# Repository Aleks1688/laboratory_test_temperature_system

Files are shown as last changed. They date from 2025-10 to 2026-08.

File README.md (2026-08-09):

# 🔬 Laboratory Test Temperature System

**Многоканальный контроллер для тестирования термопар в лабораторных условиях**




---

## 📋 Описание проекта

Устройство предназначено для **циклического измерения температуры до 10 термопар** (K-type) с передачей данных по MQTT. 

### Ключевая особенность — работа под высоким напряжением ⚡

Термопары устанавливаются **непосредственно на выводы LED и других компонентов**, которые находятся под потенциалом **400–500 В** (фаза сети 230 В AC или повышающий преобразователь LED-драйверов). Поэтому:

- **Оба провода каждой термопары (TC+ и TC-) коммутируются через DPDT реле**
- Полная **гальваноразвязка** между высоковольтной стороной термопар и низковольтной частью (ESP32)
- Питание датчика MAX31856 — от **изолированного DC-DC** (TMA-0505)
- SPI-сигнал проходит через **цифровой изолятор ISO7741**
- PCB спроектирована с учётом **creepage/clearance** для усиленной изоляции

---

## 🏗 Архитектура системы

```
┌────────────────────────── ЗОНА ВЫСОКОГО НАПРЯЖЕНИЯ ───────────────────────────┐
│                                                                                 │
│   Термопара 1 (400-500В) ──┐                                                    │
│                            ├── IM03GR (DPDT) ───┬── [100Ω] ──┬── MAX31856 T+ │
│   Термопара 1 (400-500В) ──┘                    │           │                │
│                                                 ├── IM03GR    ├── [100Ω] ──┼── MAX31856 T- │
│   Термопара 2 ...                                │           │                │
│   ...                                            GND(A)     C_filter          │
│   Термопара 10                                                       │         │
│                                                              ┌────────────┐  │
│                                                              │  MAX31856  │  │
│                                                              │ (SPI slave)│  │
│                                                              └─────┬──────┘  │
│                                                                    │ SPI      │
│                                                        ┌───────────▼────────┐ │
│                                                        │     ISO7741        │ │
│                                                        │ (4ch digital iso)  │ │
│                                                        └───────────┬────────┘ │
├────────────────────────── ЗОНА НИЗКОГО НАПРЯЖЕНИЯ ─────────────────────────────┤
│                                                                    │ SPI      │
│                                                        ┌───────────▼────────┐ │
│                                                        │     ESP32-J2       │ │
│                                                        │  WiFi + MQTT       │ │
│                                                        └────────────────────┘ │
│                                                                                 │
│  Изолированное питание: +5V ──► TMA-0505 ──► ±5V_iso ──► MAX31856 + катушки  │
│                                                                                 │
└─────────────────────────────────────────────────────────────────────────────────┘
```

---

## 🧩 Схема электрическая принципиальная

### Основные компоненты

| Компонент | Тип | Назначение | Кол-во |
|---|-----|---|---|
| **ESP32-J2** | Модуль Wi-Fi/Bluetooth SoC | Главный контроллер, WiFi, MQTT | 1 |
| **MAX31856** | АЦП термопар | Преобразование температура→цифра (SPI) | 1 |
| **ISO7741** | Цифровой изолятор | Гальваноразвязка SPI (4 канала) | 1 |
| **IM03GR** | Сигнальное реле DPDT | Коммутация TC+ и TC- каждого канала | **10** |
| **TMA-0505** | DC-DC изолированный | ±5V изолированное питание | 1 |
| **MIC5205-2.5** | LDO | 5V → 2.5V (референс MAX31856) | 1 |
| **AO3401A** | P-MOSFET | Ключ питания аналоговой части | 1 |
| **74HC595D** | Сдвиговый регистр | Управление 20 LED индикаторами | 1-2 |

### Драйвер реле (на канал)

Каждое реле IM03GR управляется через NPN-транзистор:

```
GPIO ESP32 ──[1kΩ]──┬── NPN (BC847 / MMBT3904)
                    │         │
                   GND       Collector ──[Катушка IM03GR]── +5VA_iso
                                          │
                                    [Flyback 1N4148W]
```

- Ток катушки IM03GR = **28 мА** (5V / 178Ω) → GPIO ESP32 не тянет напрямую!
- Flyback диод защищает транзистор от выброса ЭДС самоиндукции

---

## 💡 Индикация

У каждого разъёма термопары — **2 светодиода**:

| Цвет | Значение | Условие |
|---|---|---|
| 🟢 **Зелёный** | Канал активен, идёт замер | `currentRelay == thisChannel` |
| 🔴 **Красный** | Ошибка термопары | Fault бит от MAX31856 (обрыв, короткое замыкание) |
| ⚫ **Погашены** | Канал ждёт очереди | Default state |

LED управляются через **74HC595 сдвиговый регистр** (3 GPIO → 20 LED).

---

## 📦 BOM (Bill of Materials)

### Цифровая часть (низковольтная зона)

| Qty | Компонент | Параметры | Корпус | Примечание |
|-----|---|---|---|---|
| 1 | ESP32-J2 | Wi-Fi/BLE модуль | Модуль | Основной МК |
| 1 | MAX31856 | ADC термопар, SPI | SSOP-20 | K-type, J-type... |
| 1 | ISO7741 | 4-канальный цифровой изолятор | SOIC-16 | 5kVrms, SPI развязка |
| 1 | MIC5205-2.5YM5 | LDO 2.5V, 500mA | SOT-23-5 | Референс MAX31856 |
| 1 | AO3401A | P-MOSFET, 30V, 4A | SOT-23 | Ключ питания |
| 1 | TMA-0505S | DC-DC ±5V изолированный | SIP-4/DIP | ±5V_iso для analog part |
| 2 | 74HC595D | 8-bit shift register | SOIC-16 | Управление LED (20 шт) |

### Высоковольтная часть (зона термопар)

| Qty | Компонент | Параметры | Корпус | Примечание |
|-----|---|---|---|---|
| **10** | **IM03GR** | Реле сигнальное DPDT, 5V, 178Ω | **SMT gull-wing** | TE 1-1462037-4, 1800V изол. |
| 10 | MMBT3904 / BC847S | NPN транзистор | SOT-23 / SOT-23-6 | Драйвер катушки (28мА) |
| 10 | 1N4148W / LL4148 | Flyback диод | SOD-123 / SOT-23 | Защита от ЭДС |
| 10 | 1kΩ | Резистор базы | 0805 | |
| 10 | 100Ω | Последовательный вход TC | 0805 | Защита MAX31856 |
| 20 | LED 0603 | Зелёный + красный | 0603 | Индикация каналов |
| 20 | 470Ω – 1kΩ | Резисторы LED | 0805 | I_LED ≈ 2-3мА |

### Пассивные компоненты

| Qty | Компонент | Значение | Примечание |
|-----|---|---|---|
| 4 | 0.1µF керамический | Декаплинг по питанию | 0603/0805 |
| 4 | 0.01µF – 0.1µФ | Фильтр входов TC | 0603 |
| 2 | 100кΩ | Pull-up/pull-down | 0603 |

### Разъёмы и механика

| Qty | Компонент | Примечание |
|-----|---|---|
| 10 | Разъём термопары 2-pin | Штырьковой или клеммник |
| 1 | Разъём ESP32-J2 | Для программирования |
| 1 | DIN-рейка корпус | Компактный, ширина ~4-6 TE |

> **Полный BOM с артикулами поставщиков** будет добавлен после финализации схемы.

---

## ⚙️ Программная архитектура

### FreeRTOS задачи

```
┌─────────────┐    семафор     ┌──────────────────┐    семафор     ┌──────────┐
│  relayTask  │ ──────────────► │  tempSensorTask  │ ──────────────► │ mqttTask │
│  (приоритет 1)│               │  (приоритет 2)   │               │ (пrio 1) │
└─────────────┘                 └──────────────────┘                └──────────┘
      │                                 │                               │
      ▼                                 ▼                               ▼
 Циклическое                     Чтение MAX31856                  WiFi+MQTT
 переключение 10                 TC, CJ Temp, Fault               JSON publish
 реле с паузой                   Стабилизация 100ms               в топики:
 на разрядку 200ms                                                /temp/data
                                                                  /temp/status
```

### Логика работы цикла

1. **relayTask**: Все реле OFF → пауза 200мс (разрядка!) → включить следующее → семафор → ждать 5 сек
2. **tempSensorTask**: Ждёт семафор → пауза 100мс (стабилизация сигнала) → читать TC/CJ/fault → обновить LED → семафор MQTT
3. **mqttTask**: Держит соединение → получает данные → формирует JSON → публикует

### MQTT топики

| Топик | Формат | Периодичность |
|---|---|---|
| `temperature_system/data` | JSON: `{ch, temp_cj, fault, ts}` | Каждые ~5 сек (на канал) |
| `temperature_system/status` | `"online"` / `"offline"` (LWT) | При изменении |

### JSON формат данных

```json
{
  "channel": 3,
  "tc_temp": 245.67,
  "cj_temp": 32.15,
  "fault": 0,
  "timestamp": "2026-08-09T14:30:00"
}
```

Коды fault: `0`=OK, `1`=open circuit, `2`=short to GND, `3`=short to VCC.

---

## 🔌 Распиновка GPIO (новая версия, 10 каналов)

### ESP32-J2 назначение пинов

| GPIO | Функция | Зона |
|---|---|---|
| 5 | CS (MAX31856, через ISO7741) | Digital |
| 18 | MOSI (через ISO7741) | Digital |
| 19 | MISO (через ISO7741) | Digital |
| 23 | SCK (через ISO7741) | Digital |
| 32 | Relay CH1 driver | Digital out |
| 33 | Relay CH2 driver | Digital out |
| 25 | Relay CH3 driver | Digital out |
| 26 | Relay CH4 driver | Digital out |
| 27 | Relay CH5 driver | Digital out |
| 14 | Relay CH6 driver | Digital out |
| 22 | Relay CH7 driver | Digital out |
| 21 | Relay CH8 driver | Digital out |
| 17 | Relay CH9 driver | Digital out |
| 16 | Relay CH10 driver | Digital out |
| 13 | 74HC595 DATA | Digital out |
| 12 | 74HC595 CLK | Digital out |
| 15 | 74HC595 LATCH | Digital out |
| 4 | DRDY (MAX31856) | Digital in |
| 2 | FAULT (MAX31856) | Digital in |

> **Примечание:** Final pinout будет определён после трассировки PCB. Некоторые пины могут измениться.

---

## 🛠️ Сборка и прошивка

### Требования

- [PlatformIO Core](https://platformio.org/) (CLI или VS Code extension)
- [KiCad](https://www.kicad.org/) 8.x+ (для редактирования схемы/PCB)
- USB-UART адаптер для прошивки ESP32

### Прошивка

```bash
# Клонирование
git clone https://github.com/Aleks1688/laboratory_test_temperature_system.git
cd laboratory_test_temperature_system

# Создать secrets.h (см. ниже)
cp include/secrets.h.example include/secrets.h
# Отредактировать: WIFI_SSID, WIFI_PASSWORD, MQTT_SERVER_IP, etc.

# Сборка и прошивка
pio run -t upload --environment esp32dev

# Монитор последовательного порта
pio device monitor -b 115200
```

### Конфигурация WiFi/MQTT (`include/secrets.h`)

```cpp
#ifndef SECRETS_H
#define SECRETS_H

// WiFi
#define WIFI_SSID "YourNetworkName"
#define WIFI_PASSWORD "YourPassword"

// MQTT Broker
#define MQTT_SERVER_IP "192.168.x.x"
#define MQTT_SERVER_PORT 1883

#endif // SECRETS_H
```

> ⚠️ **`secrets.h` в `.gitignore`!** Не загружайте пароли в GitHub!

---

## 📐 Требования безопасности к PCB

Для рабочего напряжения **500В AC/DC** (Pollution Degree 2, лаборатория):

| Параметр | Минимум (IEC 60664-1) | Реализовано |
|---|---|---|
| Clearance (воздух между проводниками) | 2.5 мм | 3.0+ мм |
| Creepage (по поверхности PCB) | 2.5 мм | 4.0 мм + slotting |
| Между каналами термопар | 2.5 мм | **5.0 мм** (разные потенциалы!) |
| Изолированная ↔ Неизолированная зона | 4.0 мм | **6.0 мм + слот** |
| Конформное покрытие | Recommended | **Обязательно** |

### Slotting (увеличение creepage)

Между дорожками разных каналов и между зонами напряжения — **фрезерованные вырезы** в PCB:

```
  Канал 1 (TC)        ╔═══════╗        Канал 2 (TC)        ╔═══════╗
  [+] [-]             ║ ВЫРЕЗ ║        [+] [-]             ║ ВЫРЕЗ ║
    │                 ║ 2мм   ║          │                 ║ 2мм   ║
    └─────────────────╨───────╨──────────┴─────────────────╨───────╨───
                        ↑ creepage теперь через воздух (больше!)
```

---

## 📂 Структура репозитория

```
laboratory_test_temperature_system/
├── README.md                  ← Этот файл
├── platformio.ini             # Конфигурация PlatformIO (ESP32, Arduino framework)
├── .gitignore
│
├── src/                      # Исходный код прошивки
│   ├── main.cpp              # Точка входа, создание задач FreeRTOS
│   ├── relay_control.cpp     # Управление реле (цикл 10 каналов)
│   ├── temp_sensor.cpp       # Чтение MAX31856
│   └── mqtt_client.cpp       # WiFi + MQTT публикация
│
├── include/                  # Заголовочные файлы
│   ├── config.h              # Пины, тайминги, константы
│   ├── secrets.h.example     # Шаблон для WiFi/MQTT (см. secrets.h)
│   ├── relay_control.h
│   ├── temp_sensor.h
│   └── mqtt_client.h
│
├── lib/                      # Локальные библиотеки (пока пусто)
│
├── test/                     # Unit-тесты PlatformIO
│
├── hardware/                 # KiCad проект (СКОРО)
│   ├── temperature_controller.kicad_pro
│   ├── temperature_controller.kicad_sch
│   ├── temperature_controller.kicad_pcb
│   └── libs/                 # KiCad символы/footprints
│       ├── IM03GR.kicad_sym
│       ├── IM03GR.kicad_footprint
│       └── ...
│
├── docs/                     # Документация и даташиты
│   ├── IM03GR_datasheet.pdf      # AXICOM/TE реле (НОВОЕ)
│   ├── CPC2014N_datasheet.pdf    # Старое SSR реле (для истории)
│   ├── ISO7741_datasheet.pdf     # Цифровой изолятор
│   ├── TMA-0505_datasheet.pdf    # DC-DC изолированный
│   ├── MAX31856_datasheet.pdf    # АЦП термопар
│   └── images/
│       ├── schematic.png          # Принципиальная схема
│       ├── pcb_top.png            # PCB top layer
│       └── pcb_bottom.png         # PCB bottom layer
│
└── images/                   # Для README (скриншоты)
```

---

## 🔄 История изменений (Changelog)

### v2.0 — Переделка на механические реле (в процессе)
- ❌ CPC2014N SSR ×12 → ✅ **IM03GR DPDT ×10** (1800V изоляция контакт-катушка)
- ❌ 12 каналов → ✅ **10 каналов**
- ➕ **DPDT коммутация обоих проводов TC+ и TC-** (безопасность при 500В!)
- ➕ **LED индикация** на каждый канал (активный / fault)
- ➕ **Драйверы реле** (NPN + flyback диод)
- ➕ **74HC595** для управления 20 LED
- ➕ **README + документация + даташиты**

### v1.0 — Исходная версия (октябрь 2025)
- 12× CPC2014N SSR реле
- ESP32 + MAX31856 + ISO7741 + TMA-0505
- FreeRTOS задачи: relay / tempSensor / mqtt
- MQTT публикация JSON
- KiCad схема и PCB (CPC2014N_PCB.kicad_sch)

---

## ⚠️ Предупреждения

### Электробезопасность ⚡⚡⚡
Это устройство работает с **опасным напряжением 400–500 В**. При неправильной сборке или использовании существует риск:
- **Поражения электрическим током**
- **Возгорания** при пробое изоляции
- **Повреждения измерительного оборудования**

**Всегда:**
- Соблюдайте creepage/clearance расстояния на PCB
- Используйте конформное покрытие высоковольтной зоны
- Проверяйте изоляцию мегомметром перед первым включением
- Работайте под присмотром квалифицированного персонала

### Лицензия

MIT License — см. файл [LICENSE](LICENSE).

---

## 👤 Автор

**Aleks1688 (Razin)**  
Лаборатория тестирования LED-компонентов  
*Проект создан для внутренних нужд лаборатории*

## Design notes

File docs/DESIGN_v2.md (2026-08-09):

# 📐 Design Document v2.0 — Thermocouple Test Controller

## Обновлено: 2026-08-09

---

## 1. Выбор компонентов — Финализация

### 1.1 Реле: AXICOM IM03GR (TE 1-1462037-4)
| Параметр | Значение |
|---|---|
| Тип | Signal Relay, **DPDT (2 Form C / 2CO)**
| Катушка | 5V DC, **178Ω**, **28mA**, 140mW
| Контакты | PdRu+Au (золото), бифуркационные
| Номинал | **220VDC / 250VAC**, 2A max
| Изоляция контакт-катушка | **1800 Vrms** ✅
| Изоляция смежные контакты | 1000 Vrms
| Корпус | **SMT gull-wing**, 10×6×5.65mm
| Монтаж | Reflow до 260°C

**Использование DPDT:** POLE1 = TC+, POLE2 = TC- (оба провода коммутируются!)

### 1.2 Светодиоды индикации: Аксиальный Pilot LED 2×3×4.7mm
| Параметр | Значение |
|---|---|
| Тип | Axial "pilot light" LED, диффузный квадратный корпус |
| Размер | **2×3×4.7mm** (или 2×5×7mm вариант) |
| Монтаж | **Through-hole**, выводы через PCB, припаян снизу |
| Расположение | На верхней панели: отверстие Ø2-2.3mm, LED снизу, светит вверх |
| Цвета | 🟢 Зелёный (активный канал), 🔴 Красный (fault) |
| Ток | ~2-5мА (резистор 680Ω-1.5kΩ от 3.3V или 5V) |

**Всего:** 10 каналов × 2 цвета = **20 LED**

### 1.3 Драйвер реле: NPN транзистор
| Параметр | Значение |
|---|---|
| Тип | **BC847S** (dual NPN в SOT-23-6) или **MMBT3904** (SOT-23) |
| Ic max | 500mA (достаточно для 28мА катушки) |
| hFE | >100 (при Ic=10мА) → Ib < 0.3мА от GPIO |
| Резистор базы | **1kΩ** (Ib ≈ 2.6мА при 3.3V GPIO) |
| Flyback диод | **1N4148W** (SOD-123) или **LL4148** (MELF) |

**BC847S = 2 NPN в одном корпусе** → 5 штук на 10 реле вместо 10 отдельных!

### 1.4 Драйвер LED: 74HC595 сдвиговый регистр
| Параметр | Значение |
|---|---|
| Тип | **74HC595D** (SOIC-16) или **74HC595PW** (TSSOP-16) |
| Количество | **3 штуки** (3×8bit = 24 бита, используем 20) |
| Подключение | Каскадом: QH'→DS следующего |
| Управление | **3 GPIO**: DATA (SER), CLK (SRCLK), LATCH (RCLK) |
| Напряжение | 3.3V логика от ESP32 (HC-серия tolerant) |
| Ток вывода | ±6mA (хватит для LED через резистор) |

**Распределение бит 74HC595:**
```
Chip 1 (Q0-Q7):   CH1_ACTIVE, CH2_ACTIVE, CH3_ACTIVE, CH4_ACTIVE, CH5_ACTIVE, CH6_ACTIVE, CH7_ACTIVE, CH8_ACTIVE
Chip 2 (Q0-Q7):   CH9_ACTIVE, CH10_ACTIVE, CH1_FAULT, CH2_FAULT, CH3_FAULT, CH4_FAULT, CH5_FAULT, CH6_FAULT
Chip 3 (Q0-Q1):   CH7_FAULT, CH8_FAULT, CH9_FAULT, CH10_FAULT, [свободно x4]
```

---

## 2. GPIO Map — Финальное распределение

### ESP32-J2 доступные GPIO (исключая strapping/flash):
Используем только "безопасные" GPIO без странных побочек при старте:

| GPIO | Функция | Зона | Примечание |
|---|---|---|---|
| **SPI (через ISO7741):** ||||
| 5 | CS_MAX | Digital out | MAX31856 Chip Select |
| 18 | SPI_MOSI | Digital out | → ISO7741 INA → MAX31856 SDI |
| 19 | SPI_MISO | Digital in | MAX31856 SDO → ISO7741 OUTA → GPIO19 |
| 23 | SPI_SCK | Digital out | → ISO7741 INB → MAX31856 SCK |
| **Реле (драйверы NPN):** ||||
| 32 | RELAY_CH1 | Out | → R_base Q1 → IM03GR #1 катушка |
| 33 | RELAY_CH2 | Out | → IM03GR #2 |
| 25 | RELAY_CH3 | Out | → IM03GR #3 |
| 26 | RELAY_CH4 | Out | → IM03GR #4 |
| 27 | RELAY_CH5 | Out | → IM03GR #5 |
| 14 | RELAY_CH6 | Out | → IM03GR #6 |
| 22 | RELAY_CH7 | Out | → IM03GR #7 |
| 21 | RELAY_CH8 | Out | → IM03GR #8 |
| 17 | RELAY_CH9 | Out | → IM03GR #9 |
| 16 | RELAY_CH10 | Out | → IM03GR #10 |
| **LED драйвер (74HC595 ×3):** ||||
| 13 | LED_DATA (SER) | Out | 74HC595 serial data in |
| 12 | LED_CLK (SRCLK) | Out | Shift register clock |
| 15 | LED_LATCH (RCLK) | Out | Output latch strobe |
| **MAX31856 статус:** ||||
| 4 | DRDY | Digital in | Data Ready (опционально) |
| 2 | FAULT | Digital in | Fault output от MAX31856 |
| **Питание/управление:** ||||
| 13 | PWR_KEY | Out | AO3401A gate (включить изолированную часть) |

**Итого: 10 + 3 + 4 + 2 + 2 = 21 GPIO** ← ESP32-J2 потянет легко ✅

> ⚠️ GPIO 12 (HS2_DATA2) — избегаем! Влияет на flash voltage при старте.
> GPIO 0, 2, 5, 12 — strapping pins, используем осторожно (2 и 5 OK как обычные GPIO после boot).

---

## 3. Принципиальная схема — Описание по секциям

### Секция A: Питание (верх слева на схеме)
```
+5V ──┬── C1 0.1µF ── GND
      │
      ├── U15 MIC5205-2.5YM5 (IN=5V, OUT=2.5V)
      │    IN EN OUT BP GND
      │    │   │   │   │   │
      │    +5V HI 2.5VA C8 0.1µF GND
      │              │
      │              C6 0.1µF ── GND
      │
      └── U16 TMA-0505S (изолированный DC-DC)
           Vin+ Vin- Vout+ Vout-
           │     │     │      │
          +5V   GND  +5VA   -5VA (GND_A)
                    │       │
                   C7,C8  0.1µF each to GND_A
```
- **2.5VA** → референс MAX31856 (pin BIAS)
- **±5VA (GND_A)** → питание MAX31856 + катушки реле + ISO7741 сторона B

### Секция B: ESP32-J2 модуль (центр верх)
```
J4: ESP32-J2 разъём (все GPIO выведены)
├── 3V3 (от внутреннего LDO ESP32)
├── GND
├── EN, BOOT, RXD, TXD (для прошивки)
└── GPIO 2,4,5,12-33 (как в таблице выше)
```

### Секция C: Цифровой изолятор ISO7741 (справа верх)
```
U13: ISO7741DW (SOIC-16)
 Side A (LV):            Side B (HV_iso):
 INA  ← GPIO18 (MOSI)   OUTA → MAX SDI (pin 3)
 INB  ← GPIO23 (SCK)    OUTB → MAX SCK (pin 5)
 INC  ← MAX SDO (OUTC)  → GPIO19 (MISO)
 IND  ← (GND)           OUTD → (GND_A)
 VCC1 = 3V3             VCC2 = +5VA
 GND1 = GND             GND2 = GND_A
```

### Секция D: MAX31856 + защита входов (справа низ)
```
U14: MAX31856SS (TSSOP-20)
 Питание: AVDD=+5VA, DVDD=+5VA, GND=GND_A, BIAS=2.5VA
 SPI: SDI(3), SCK(5), SDO(6), CS(4)
 Аналоговые входы:
   T+ (pin 17) ── R27 100Ω ──┬── от реле (COM→NO полюс 1)
                              ├── C3 0.01µF ── GND_A
   T- (pin 18) ── R28 100Ω ──┬── от реле (COM→NO полюс 2)
                              ├── C4 0.01µF ── GND_A
 Защита:
   D1,D2: 1N4148 (T+ → AVDD, T+ → GND_A)
   D3,D4: 1N4148 (T- → AVDD, T- → GND_A)
 Статус:
   DRDY (pin 15) → GPIO4 (ESP32)
   FAULT (pin 14) → GPIO2 (ESP32)
```

### Секция E: 10× Реле IM03GR + драйверы (левая половина схемы)
```
На КАЖДЫЙ канал (пример CH1):

GPIO32 ──[R1 1kΩ]──┬── Q1a (BC847S half-A) NPN
                     │        │
                    GND      Collector ──┬── Coil_IM03GR_1 ── +5VA
                                           │
                                    [Flyback D1 1N4148W]
                                           │
                                          GND_A

IM03GR_1 (DPDT):
  Pole 1: COM1 ← TC+_CH1   NO1 ──[R_100]── MAX31856 T+
           NC1 ── открыт (никуда)
  Pole 2: COM2 ← TC-_CH1   NO2 ──[R_100]── MAX31856 T-
           NC2 ── открыт (никуда)

Повторить ×10!
```

**Размещение на PCB:** 2 ряда по 5 реле (левый и правый край платы)

### Секция F: Разъёмы термопар (нижний край PCB)
```
J2  ── TC1 (2-pin: +, -)
J3  ── TC2
...
J11 ── TC10

Тип разъёма: клеммник 5.08mm pitch (Phoenix-style) или штырьковой 2.54mm
Каждый разъём → напрямую на COM1/COM2 соответствующего IM03GR
```

### Секция G: LED индикация + 74HC595 (верхняя часть PCB)
```
U_LED1, U_LED2, U_LED3: 74HC595D (SOIC-16) — каскадом

Kаскад:
  GPIO13 (DATA) → U_LED1 DS (pin 14)
  GPIO12 (CLK)  → все SRCK (pin 11) параллельно
  GPIO15 (LAT)  → всех RCLK (pin 12) параллельно
  U_LED1 QH'(pin 9) → U_LED2 DS (pin 14)
  U_LED2 QH'(pin 9) → U_LED3 DS (pin 14)

Питание: VCC=3V3, GND=GND
OE' (pin 13) → GND (всегда включен)
SRCLR' (pin 10) → +3V3 (не сбрасывать)

LED (TH, 2×3×4.7mm, припаяны снизу, светят вверх):
  U_LED1 Q0 → [680Ω] → LED_CH1_GREEN (катод→GND)
  U_LED1 Q1 → [680Ω] → LED_CH2_GREEN
  ...
  U_LED2 Q2 → [680Ω] → LED_CH1_RED
  ...
  U_LED3 Q3 → [680Ω] → LED_CH10_RED
```

---

## 4. Конструкция PCB

### 4.1 Форм-фактор
- **Корпус:** DIN-рейка компактный (предположительно 4-6 TE модулей, ~72-108mm ширина)
- **Размеры PCB:** ориентировочно **100×80 мм** (точные размеры после выбора корпуса)
- **Слои:** 2 (Top + Bottom), толщина **1.6мм**
- **Материал:** FR-4 стандартный

### 4.2 Размещение по слоям

#### TOP LAYER (видимая сверху, лицевая панель):
```
┌──────────────────────────────────────────────────────┐
│  [TC1] ●○  [TC2] ●○  [TC3] ●○  [TC4] ●○  [TC5] ●○  │ ← Разъёмы термопар
│   ○G   ○R   ○G   ○R   ○G   ○R   ○G   ○R   ○G   ○R   │ ← LED отверстия (G=green, R=red)
│                                                      │
│  [TC6] ●○  [TC7] ●○  [TC8] ●○  [TC9] ●○  [TC10]●○  │
│   ○G   ○R   ○G   ○R   ○G   ○R   ○G   ○R   ○G   ○R   │
│                                                      │
│  ┌──────────────── ESP32 + ISO7741 + MAX31856 ─────┐ │
│  │  (центральная зона, безопасная)                  │ │
│  └──────────────────────────────────────────────────┘ │
│                                                      │
│  ┌──── 74HC595 ×3 + пассивки ──────────────────────┐ │
│  │                                                  │ │
│  └──────────────────────────────────────────────────┘ │
└──────────────────────────────────────────────────────┘
```

#### BOTTOM LAYER (паяльная сторона, скрыта внутри корпуса):
```
┌──────────────────────────────────────────────────────┐
│  [IM03GR×5]         [IM03GR×5]                       │ ← Рле левый+правый ряд
│   Q1-Q5              Q6-Q10                           │
│   D1-D5 flyback      D6-D10 flyback                   │
│   R_base ×5          R_base ×5                        │
│                                                      │
│  [Транзисторы BC847S ×5]  [BC847S ×5]               │ ← Драйверы реле
│                                                      │
│  [Резисторы LED ×20]                                 │ ← Для 20 светодиодов
│                                                      │
│  [LED TH ×20 — припаяны здесь, выводы сквозные ↑↑↑]  │ ← Светят наверх!
│                                                      │
│  [TMA-0505] [MIC5205] [AO3401A]                      │ ← Питание
│  [Конденсаторы декаплинг]                             │
└──────────────────────────────────────────────────────┘
```

### 4.3 Отверстия для LED (сквозные, под установку TH-диодов)

```
  Вид сверху (Top layer):        Поперечное сечение:
                                    
  ┌───┐                            ════════ Top (маска)
  │ ○ │ ← Ø2.0-2.3mm отверстие      │       │
  └───┘                            │  LED  │ ← корпус 2×3mm
       ↑                           │ диф.  │
  LED светит                       ════════ Bottom (пятачки)
  через отверстие                  паяльник сюда ↑
  
  Диаметр отверстия: 2.0mm (под выводы 0.45-0.5mm + зазор)
  Размер пятачка: Ø3mm (annular ring)
  Расстояние между центрами LED: 5mm (минимум)
```

### 4.4 Зоны безопасности на PCB

```
╔══════════════════ HV ZONE (термопары 400-500V) ══════════════════╗
║                                                                   ║
║  J2-J11 (разъёмы TC)                                              ║
║       │                                                           ║
║       ▼                                                           ║
║  [IM03GR ×10] ← коммутация TC                                     ║
║       │                                                           ║
║  ═════╧══════════════════ ISOLATION BARRIER ═══════╧════════════  ║
║       │              (slotting + creepage ≥6mm)    │              ║
║  [R_100Ω] ×10                                        [R_100Ω] ×10 ║
║       │                                                           ║
║       ▼                                                           ║
║  [MAX31856] ← сидит на GND_A (изолированная земля)                ║
║       │                                                           ║
║  ═════╧════════════════ ISO7741 DIGITAL ISOLATION ═════╧════════  ║
║       │                        (5kVrms)              │              ║
║  [ESP32-J2] ← сидит на GND (земля контроллера)                     ║
║                                                                   ║
║  [74HC595 ×3] ← тоже на GND (безопасная зона)                     ║
║                                                                   ║
╚═══════════════════════════════════════════════════════════════════╝
```

### 4.5 Slotting (вырезы для увеличения creepage)

Между HV зоной (реле/разъёмы TC) и LV зоной (MAX31856/ESP32):

```
  Top view:                    Cross-section:
                                
  [HV дорожки]                 ═══ Top copper ═══
       │                         │
  ╔═════╧══════╗                  │  AIR (clearance)
  ║  SLOT      ║  ← фреза 2mm wide, сквозной  │
  ║  (вырез)   ║                  │
  ╚═════╤══════╝                  ═══ Bottom copper ═══
       │                           
  [LV дорожки]                        
       
  Creepage теперь идёт: по top → вниз через стенку slot → по bottom → вверх
  Эффективная длина >> прямой по поверхности!
```

---

## 5. Порядок сборки

### 5.1 SMT компоненты (сначала нижнюю сторону!)
1. Напечатать пасту на Bottom layer
2. Смонтировать: IM03GR ×10, BC847S ×5, 1N4148W ×10, резисторы, конденсаторы, 74HC595 ×3, ISO7741, MIC5205, AO3401A
3. Reflow (или ручная пайка феном)
4. Перевернуть плату, смонтировать MAX31856 (если TSSOP на top)

### 5.2 Through-hole компоненты
1. Вставить LED ×20 снизу (ногами вверх!)
2. Вставить разъёмы термопар ×10 (сверху)
3. Вставить ESP32-J2 коннектор (сверху)
4. Паять TH components

### 5.3 Контроль
1. Визуальный осмотр
2. Проверка изоляции мегомметром (HV↔LV > 100MΩ при 500V)
3. Подать питание, проверить ток холостого хода
4. Прошить ESP32, протестировать MQTT

---

## 6. TODO — Следующие шаги

- [ ] Создать KiCad 10 проект (`.kicad_pro`)
- [ ] Создать символ IM03GR (DPDT реле SMT gull-wing)
- [ ] Создать footprint IM03GR (10×6mm, gull-wing pads)
- [ ] Создать footprint LED pilot 2×3×4.7mm (TH, сквозное)
- [ Нарисовать принципиальную схему (все секции A-G)
- [ ] Разместить компоненты на PCB
- [ ] Трассировка с учётом изоляции (slotting между зонами)
- [ ] DRC проверка
- [ ] Генерация Gerber для производства
- [ ] Обновить код прошивки под новый GPIO map

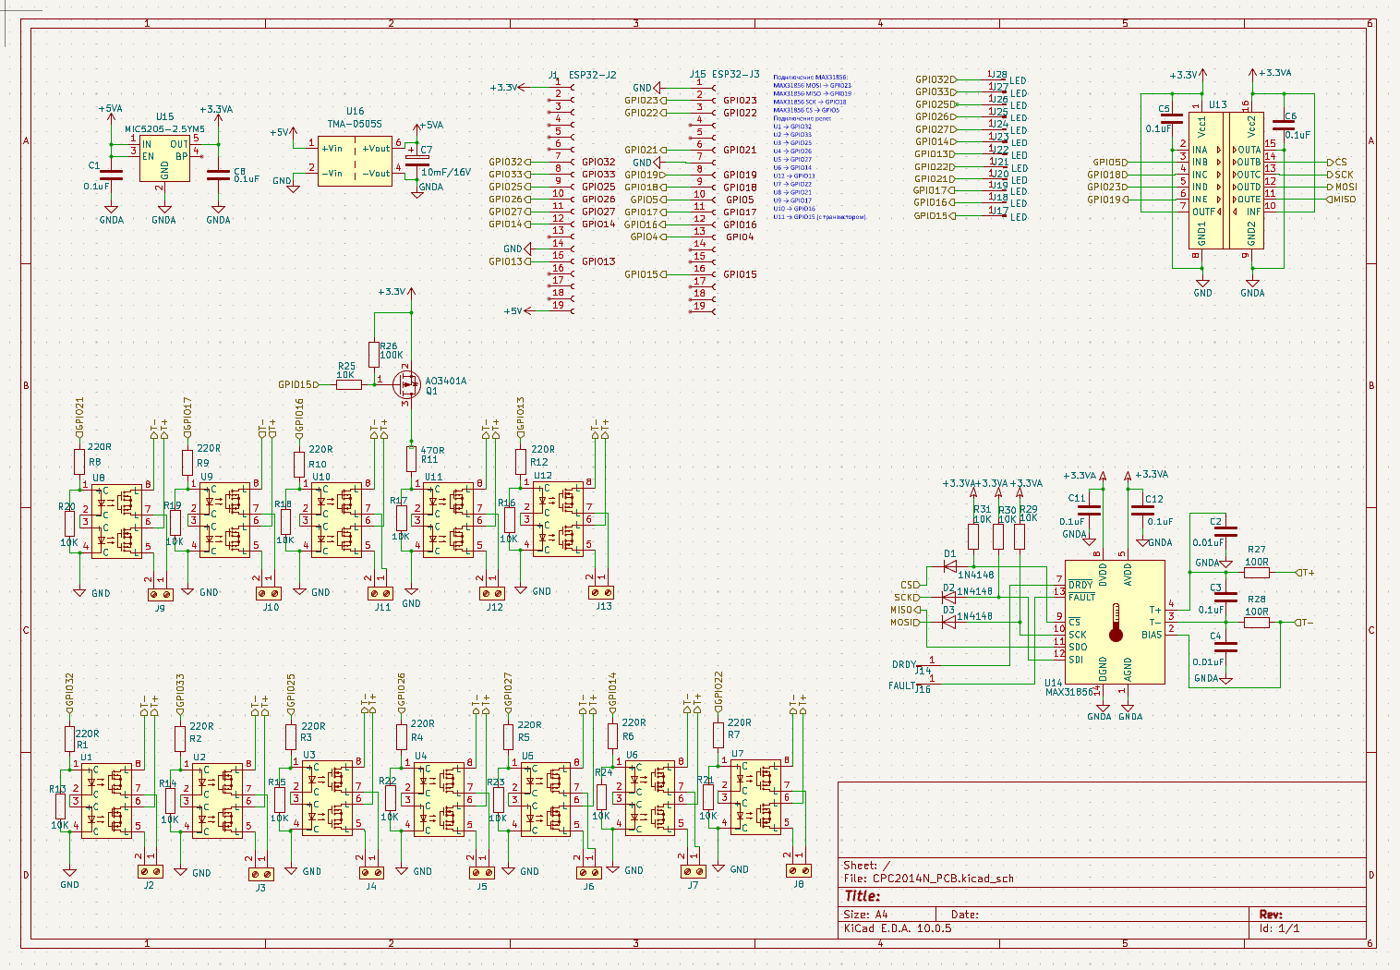
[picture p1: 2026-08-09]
docs/images/schematic_v1_CPC2014N.png

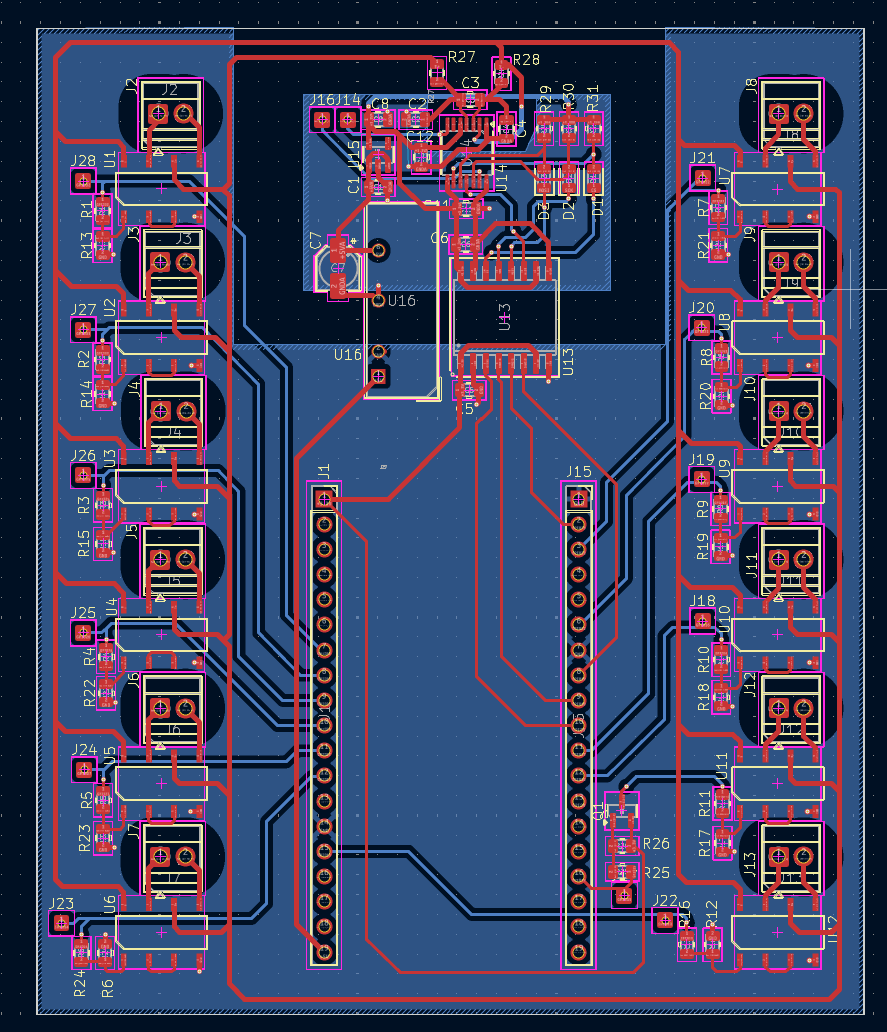
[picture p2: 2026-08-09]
docs/images/pcb_v1_CPC2014N_top.png

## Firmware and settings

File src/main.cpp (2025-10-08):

#include <Arduino.h>
#include "config.h"
#include "relay_control.h"
#include "temp_sensor.h"
#include "mqtt_client.h"

// Глобальные семафоры для синхронизации
SemaphoreHandle_t relaySem = NULL;
SemaphoreHandle_t tempSem = NULL;

// Глобальные переменные для обмена данными между задачами
uint8_t currentRelay = 0;
float lastTemp = 0.0f;
float lastCJTemp = 0.0f;
uint8_t lastFault = 0;

void setup() {
  Serial.begin(115200);
  Serial.println("\n[SYSTEM] Booting...");

  // Создаем семафоры
  relaySem = xSemaphoreCreateBinary();
  tempSem = xSemaphoreCreateBinary();

  if (relaySem == NULL || tempSem == NULL) {
    Serial.println("[FATAL] Could not create semaphores. Halting.");
    while (1);
  }
  Serial.println("[SYSTEM] Semaphores created.");

  // Инициализация модулей в правильном порядке
  setupRelays();
  setupTempSensor();
  setupMqtt();

  // Создание задач FreeRTOS
  // Задаче датчика даем приоритет повыше, чтобы она выполнялась сразу после сигнала
  xTaskCreate(relayTask, "RelayTask", 2048, NULL, 1, NULL);
  xTaskCreate(tempSensorTask, "TempSensorTask", 4096, NULL, 2, NULL);
  xTaskCreate(mqttTask, "MqttTask", 4096, NULL, 1, NULL);

  Serial.println("[SYSTEM] Setup complete. Tasks are running.");
}

void loop() {
  // Пусто. Вся логика в задачах FreeRTOS.
  // Удаляем задачу loop(), чтобы она не тратила ресурсы процессора.
  vTaskDelete(NULL);
}

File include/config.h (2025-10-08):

// данный файл описывает пины, константы

#ifndef CONFIG_H
#define CONFIG_H

// --- НАСТРОЙКИ SPI ДЛЯ MAX31856 ---
// Важно! Ты указал MOSI=18, SCK=23. Это пины HSPI.
// Стандартный VSPI использует MOSI=23, SCK=18. Оставляю как у тебя.
#define MAX_CS   5
#define MAX_MOSI 18
#define MAX_MISO 19
#define MAX_SCK  23

// --- НАСТРОЙКИ РЕЛЕ ---
// Пины для реле U1-U12
const int RELAY_PINS[] = {32, 33, 25, 26, 27, 14, 22, 21, 17, 16, 15, 13};
const int NUM_RELAYS = sizeof(RELAY_PINS) / sizeof(RELAY_PINS[0]);

// Номер реле с инвертированной логикой (P-канал).
// В массиве он 11-й, его индекс 10.
// Ты писал про GPIO12, но в конфиге был GPIO15 (U11). Оставляю U11 (индекс 10).
const int INVERTED_RELAY_INDEX = 10;

// --- НАСТРОЙКИ ДАТЧИКА ---
// Тип термопары (K, J, T, и т.д.)
#define THERMOCOUPLE_TYPE MAX31856_TCTYPE_K // K-type thermocouple

// --- ВРЕМЕННЫЕ ИНТЕРВАЛЫ (в миллисекундах) ---
// Пауза между выключением всех реле и включением следующего.
// Критически важно для предотвращения КЗ!
const int RELAY_DISCHARGE_DELAY_MS = 200;

// Общее время цикла для одного реле (измерение + отправка).
// Например, 5 секунд на каждую термопару.
const int RELAY_CYCLE_INTERVAL_MS = 5000;

// Пауза после переключения реле перед чтением температуры для стабилизации.
const int TEMP_STABILIZE_DELAY_MS = 100;

#endif // CONFIG_H

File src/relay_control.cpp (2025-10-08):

// логика переключения реле

#include "relay_control.h"
#include "config.h" // Подключаем наш файл с настройками пинов и интервалов

// Функция инициализации. Настраивает пины реле.
void setupRelays() {
  for (int i = 0; i < NUM_RELAYS; i++) {
    pinMode(RELAY_PINS[i], OUTPUT);
    // Сразу устанавливаем реле в ВЫКЛЮЧЕННОЕ состояние
    // Учитываем, что одно реле имеет инвертированную логику
    if (i == INVERTED_RELAY_INDEX) {
      digitalWrite(RELAY_PINS[i], HIGH); // Для инвертированного HIGH = ВЫКЛ
    } else {
      digitalWrite(RELAY_PINS[i], LOW); // Для обычного LOW = ВЫКЛ
    }
  }
  Serial.println("[RELAY] All relays initialized to OFF state.");
}

// Задача FreeRTOS для управления реле
void relayTask(void *pvParameters) {
  // Начинаем с последнего реле, чтобы цикл в первый раз выбрал реле с индексом 0
  currentRelay = NUM_RELAYS - 1;

  while (1) { // Бесконечный цикл задачи
    // --- ШАГ 1: БЕЗОПАСНОСТЬ - ВЫКЛЮЧИТЬ ВСЕ РЕЛЕ ---
    for (int i = 0; i < NUM_RELAYS; i++) {
      if (i == INVERTED_RELAY_INDEX) {
        digitalWrite(RELAY_PINS[i], HIGH);
      } else {
        digitalWrite(RELAY_PINS[i], LOW);
      }
    }
    
    // --- ШАГ 2: БЕЗОПАСНОСТЬ - ПАУЗА НА РАЗРЯДКУ ---
    // Даем время, чтобы контакты разомкнулись и напряжение спало.
    // Это самый важный шаг для предотвращения КЗ!
    vTaskDelay(pdMS_TO_TICKS(RELAY_DISCHARGE_DELAY_MS));

    // --- ШАГ 3: ВЫБОР СЛЕДУЮЩЕГО РЕЛЕ ---
    currentRelay = (currentRelay + 1) % NUM_RELAYS; // Циклический переход (0, 1, ..., 11, 0, 1, ...)

    // --- ШАГ 4: ВКЛЮЧЕНИЕ ОДНОГО РЕЛЕ ---
    Serial.printf("[RELAY] Switching to relay U%d (GPIO %d)...\n", currentRelay + 1, RELAY_PINS[currentRelay]);
    if (currentRelay == INVERTED_RELAY_INDEX) {
      digitalWrite(RELAY_PINS[currentRelay], LOW); // Для инвертированного LOW = ВКЛ
    } else {
      digitalWrite(RELAY_PINS[currentRelay], HIGH); // Для обычного HIGH = ВКЛ
    }

    // --- ШАГ 5: СИГНАЛ ДЛЯ СЛЕДУЮЩЕЙ ЗАДАЧИ ---
    // Говорим задаче датчика, что можно начинать измерение
    xSemaphoreGive(relaySem);

    // --- ШАГ 6: ОЖИДАНИЕ ---
    // Ждем оставшееся время цикла перед следующим переключением
    vTaskDelay(pdMS_TO_TICKS(RELAY_CYCLE_INTERVAL_MS));
  }
}

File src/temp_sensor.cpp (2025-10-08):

#include "temp_sensor.h"
#include "config.h" // Подключаем наш файл с настройками
#include <Adafruit_MAX31856.h> // Библиотека для работы с датчиком

// Создаем объект для работы с датчиком, используя пин CS из конфига
Adafruit_MAX31856 maxthermo = Adafruit_MAX31856(MAX_CS);

// Функция инициализации датчика
void setupTempSensor() {
  // Запускаем SPI. Важно! Библиотека Adafruit использует глобальный объект SPI.
  // Мы не создаем новый SPIClass, а настраиваем стандартный.
  SPI.begin(MAX_SCK, MAX_MISO, MAX_MOSI, MAX_CS);

  if (!maxthermo.begin()) {
    Serial.println("[TEMP SENSOR] FATAL: MAX31856 not found. Check wiring!");
    Serial.println("[SYSTEM] Halting.");
    while (1); // Остановка системы, если датчик не найден
  }

  maxthermo.setThermocoupleType(THERMOCOUPLE_TYPE);
  Serial.println("[TEMP SENSOR] MAX31856 initialized successfully.");
  Serial.print("[TEMP SENSOR] Thermocouple type set to: ");
  
  // Выводим тип термопары для отладки
  switch (maxthermo.getThermocoupleType()) {
    case MAX31856_TCTYPE_B: Serial.println("B"); break;
    case MAX31856_TCTYPE_E: Serial.println("E"); break;
    case MAX31856_TCTYPE_J: Serial.println("J"); break;
    case MAX31856_TCTYPE_K: Serial.println("K"); break;
    case MAX31856_TCTYPE_N: Serial.println("N"); break;
    case MAX31856_TCTYPE_R: Serial.println("R"); break;
    case MAX31856_TCTYPE_S: Serial.println("S"); break;
    case MAX31856_TCTYPE_T: Serial.println("T"); break;
    default: Serial.println("Unknown"); break;
  }
}

// Задача FreeRTOS для измерения температуры
void tempSensorTask(void *pvParameters) {
  while (1) { // Бесконечный цикл задачи
    // --- ШАГ 1: ОЖИДАНИЕ СИГНАЛА ---
    // Задача "засыпает" здесь и ждет, пока relayTask не даст семафор.
    // portMAX_DELAY означает ждать вечно.
    if (xSemaphoreTake(relaySem, portMAX_DELAY) == pdTRUE) {
      
      // --- ШАГ 2: ПАУЗА НА СТАБИЛИЗАЦИЮ ---
      // Небольшая задержка после переключения реле, чтобы сигнал термопары стабилизировался.
      vTaskDelay(pdMS_TO_TICKS(TEMP_STABILIZE_DELAY_MS));

      // --- ШАГ 3: ЧТЕНИЕ ДАННЫХ ---
      // Считываем все данные и сохраняем их в глобальные переменные.
      lastTemp = maxthermo.readThermocoupleTemperature();
      lastCJTemp = maxthermo.readCJTemperature();
      lastFault = maxthermo.readFault();

      Serial.printf("[TEMP SENSOR] Read data: TC=%.2f C, CJ=%.2f C, Fault=0x%X\n", lastTemp, lastCJTemp, lastFault);

      // --- ШАГ 4: СИГНАЛ ДЛЯ СЛЕДУЮЩЕЙ ЗАДАЧИ ---
      // Говорим задаче MQTT, что данные готовы и можно их отправлять.
      xSemaphoreGive(tempSem);
    }
  }
}

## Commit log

2025-10-07 Initial commit: project structure with relay and temp sensor code
2025-10-07 Разделил файл config.h на relay_control.h и temp_sensor.h
2025-10-07 Добавил WIFI и MQTT setup
2025-10-08 Добавил globals.h и globals.cpp создаю семафоры
2025-10-08 Инициализировал семафоры в main.cpp
2025-10-08 Добавил семафор сигнал от реле в relay_control.cpp
2025-10-08 Добавил семафоры в relay_control.cpp и temp_sensor.cpp
2025-10-08 Обновил данные для MQTT
2025-10-08 Обновил код для MQTT
2025-10-08 Обновил код полностью
2026-08-09 docs: add README, datasheets, BOM, safety requirements, project structure
    - Full README.md with architecture diagram, BOM, safety requirements
    - Datasheets: IM03GR (new relay), CPC2014N (old SSR), ISO7741, TMA-0505
    - Schematic and PCB screenshots from v1 (CPC2014N version)
    - secrets.h.example template for WiFi/MQTT config
    - MIT License with high-voltage disclaimer
    - Updated .gitignore (KiCad backups, Python cache)
    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
2026-08-09 hw: add KiCad 10 project with full schematic, symbols, footprints
    KiCad 10 project for v2.0 (IM03GR DPDT relays):
    - temperature_controller.kicad_pro (project file, net classes: HV/IsoGnd)
    - temperature_controller.kicad_sch (full schematic: 10x IM03GR + drivers
    + MAX31856 + ISO7741 + ESP32-J2 + 74HC595x3 LED driver + power)
    - custom_symbols.kicad_sym: IM03GR_DPDT symbol + PILOT_LED symbol
    - custom_footprints.kicad_mod:
    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
    [temperature_controller.kicad_sch]

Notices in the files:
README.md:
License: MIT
